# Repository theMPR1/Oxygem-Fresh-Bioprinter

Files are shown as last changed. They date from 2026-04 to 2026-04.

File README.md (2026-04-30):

# FRESH Bioprinter — Ender 5 Pro Conversion




Open-source design files for the conversion of a Creality Ender 5 Pro desktop 3D printer into a syringe extrusion bioprinter capable of FRESH (Freeform Reversible Embedding of Suspended Hydrogels) 3D bioprinting. Developed as part of a group project at the Department of Bioengineering, Imperial College London, under the supervision of Dr Ben Almquist.

The extruder is a modified Replistruder 5, with a GT2 belt drive replacing the original planetary gearbox to reduce mechanical dead zone,  an anti-backlash nut and preloaded carriage sliders to minimise axial freeplay. Motion control is provided by a Duet 3 Mainboard 6HC running RepRapFirmware 3.6.0.

For questions or issues, please open a GitHub Issue.

---

## Contributors

**Junyuan Guan** — Bioinks, Support Bath
**Magor Pocsveiler** — Extruder Design, Firmware, Mechanical Assembly  
**Vera Rachkova** — Extruder Design, Mechanical Assembly  
**Hannah Seo** — Bioinks, Support Bath  
**Hui Sin Phang** — Mechanical Build, Firmware  
**Saad S Ayub** — Presentation, Writing
**Zifeng T Guo** — Writing  
**Ricky Zhang** — Presentation, Writing  

**Supervisor:** Dr Ben Almquist, Department of Bioengineering, Imperial College London

---

## Repository Structure

```
├── CAD/
│   ├── STEP/          # Neutral format — open without Fusion 360
│   ├── STL/           # Print-ready files
│   └── Fusion/        # Native .f3d files
├── Firmware/
│   └── config/        # RepRapFirmware configuration files for Duet 3 6HC
├── Slicing/
│   └── CuraProfile/   # Ultimaker Cura profile for bioprinting
└── README.md
```

---

## Hardware

| Component | Details |
|---|---|
| Base printer | Creality Ender 5 Pro |
| Motion controller | Duet 3 Mainboard 6HC v1.02 + Duet 3 WiFi module |
| Extruder | Modified Replistruder 5 |
| Drive train | GT2 belt, 16T/48T pulleys (3:1 reduction), TR8×1.5 leadscrew |
| Syringe | Hamilton 1001 TLL (1 mL, PTFE luer-lock) |
| Needles | 34G (~90 µm ID) for acellular collagen; 30G (~150 µm ID) for cell-containing bioinks |
| Printed parts | PETG, Bambu Labs A1 |

---

## Modifications to the Replistruder 5

- Planetary gearbox and NEMA 11 replaced with GT2 belt drive and salvaged Ender 5 Pro NEMA 17
- Anti-backlash nut replacing standard TR8 lead nut
- Preloaded linear carriage sliders
- Screw-actuated belt tensioner with slotted motor mount and M3 lock screws
- TR8×1.5 leadscrew turned down on lathe (ends reduced to 5 mm, flat milled for set screw)
- Custom PETG adapter plate for mounting to Ender 5 Pro X-axis carriage

---

## Firmware

RepRapFirmware 3.x configured for Ender 5 Pro Cartesian kinematics on a Duet 3 6HC. Key parameters:

| Axis | Steps/mm | Microstepping | Max Speed | Acceleration |
|---|---|---|---|---|
| X | 80 | 64× | 30 mm/s | 50 mm/s² |
| Y | 80 | 64× | 30 mm/s | 50 mm/s² |
| Z | 400 | 16× | 10 mm/s | 20 mm/s² |
| E0 | 6400 | 16× | 5 mm/s | 10 mm/s² |

WiFi configured in access point mode (SSID: "FRESH Bioprinter", IP: 192.168.50.1).

Configuration files are in `/Firmware/config/`. Adapted from the open-source FF Finder bioprinter configuration published by the Shiwarski Tissue Engineering Lab (Zenodo DOI: [10.5281/zenodo.7496012](https://doi.org/10.5281/zenodo.7496012)).

---

## Slicing

Structures were sliced in Ultimaker Cura. The Cura profile is provided in `/Slicing/CuraProfile/`. Key print parameters:

| Parameter | Value | Rationale |
|---|---|---|
| Retraction distance | 0.05 mm | Prevents oozing at move boundaries |
| Z-hop | Enabled | Avoids disturbance of printed structures during travel |
| End retraction | 2 mm relative | Decompresses fluid column after print |
| X/Y microstepping | 64× | Increased positioning resolution |

---

## Bill of Materials

### Extruder & Motion Components (Magor Pocsveiler)

| Item | Qty | Supplier | Part No. | Link |
|---|---|---|---|---|
| TR8×1.5 Lead Screw Nut (Anti-backlash) | 1 | IGUS | JFRM-LC-0001-TR8X1.5 | [Link](https://www.igus.co.uk/articlerouter?artnr=JFRM-LC-0001-TR8X1.5) |
| TR8×1.5 Lead Screw 1000mm | 1 | IGUS | PTGSG-08X1.5-01-R-ES | [Link](https://www.igus.co.uk/articlerouter?artnr=PTGSG-08X1.5-01-R-ES) |
| Rail Carriage (Preloaded) | 2 | IGUS | NW-01-27-P | [Link](https://www.igus.co.uk/articlerouter?artnr=NW-01-27-P) |
| Rail 100mm | 1 | IGUS | NS-01-27 | [Link](https://www.igus.co.uk/articlerouter?artnr=NS-01-27) |
| Plain Flange Bearing | 2 | RS Components | 2725067 | [Link](https://uk.rs-online.com/web/p/products/2725067) |
| Plain Bearing | 2 | RS Components | 2725190 | [Link](https://uk.rs-online.com/web/p/products/2725190) |
| M3 Washers (pack of 100) | 1 | RS Components | 189620 | [Link](https://uk.rs-online.com/web/p/products/189620) |
| M3 Thin Nuts (pack of 250) | 1 | RS Components | 4830338 | [Link](https://uk.rs-online.com/web/p/products/4830338) |
| M3×0.5 16mm Socket Head (pack of 200) | 1 | RS Components | 4679818 | [Link](https://uk.rs-online.com/web/p/products/4679818) |
| M4×0.7 8mm Countersunk Head (pack of 100) | 1 | RS Components | 281215 | [Link](https://uk.rs-online.com/web/p/products/281215) |
| M4 Nuts (pack of 250) | 1 | RS Components | 525896 | [Link](https://uk.rs-online.com/web/p/products/525896) |
| 5mm Radial Bearing | 1 | RS Components | 74776 | [Link](https://uk.rs-online.com/web/p/products/74776) |
| Thrust Bearing 8mm Bore | 2 | Gears and Sprockets | 4255-282 | — |
| GT2 48T Pulley | 1 | Gears and Sprockets | 6001-061 | — |
| GT2 16T Pulley | 1 | Gears and Sprockets | 6001-001 | — |
| Duet 3 6HC Mainboard | 1 | Ooznest | — | [Link](https://ooznest.co.uk) |
| Duet 3 WiFi Module | 1 | Ooznest | — | [Link](https://ooznest.co.uk) |

### Consumables & Wet Lab (Vera Rachkova & Junyuan Guan)

| Item | Qty | Supplier | Part No. | Link |
|---|---|---|---|---|
| Hamilton 1000 Series Gastight Syringe TLL 1mL | 1 | Fisher Scientific UK | 81320 | [Link](https://www.fishersci.co.uk/shop/products/hamilton-1000-series-gastight-syringes-luer-lock-syringes-tll-termination-14/10772361) |
| 34G Dispensing Needle Techcon (pack of 50) | 1 | Adhesive Dispensing Ltd | TE734025PK | [Link](https://www.adhesivedispensing.co.uk/34g-precision-te-general-purpose-tip-lime-te734-9607-p.asp) |
| 30G Dispensing Needle Techcon (pack of 50) | 1 | Adhesive Dispensing Ltd | TE730050PK | [Link](https://www.adhesivedispensing.co.uk/30g-precision-te-general-purpose-tip-lavender-te730-9544-p.asp) |
| Blender (gelatin microparticle preparation) | 1 | Argos | — | [Link](https://www.argos.co.uk/product/2849520) |
| Gelatin from porcine skin, ~300 Bloom, Type A BioReagent (100g) | 1 | Sigma-Aldrich UK | G1890-100G | [Link](https://www.sigmaaldrich.com/GB/en/product/sigma/g1890) |
| Cell Strainer 40 µm nylon mesh, sterile (pack of 50) | 1 | Sigma-Aldrich UK | CLS431750 | [Link](https://www.sigmaaldrich.com/GB/en/product/sigma/cls431750) |

---

## Dependencies

- [RepRapFirmware 3.x](https://github.com/Duet3D/RepRapFirmware)
- [Ultimaker Cura](https://ultimaker.com/software/ultimaker-cura) (open-source)
- [Fusion 360](https://www.autodesk.com/products/fusion-360) (for native CAD files; STEP files provided for licence-free access)

---

## Related Publications

- Shiwarski, D.J. et al. "3D bioprinting of collagen-based high-resolution internally perfusable scaffolds for engineering fully biologic tissue systems." *Science Advances*, 2025. DOI: [10.1126/sciadv.adu5905](https://doi.org/10.1126/sciadv.adu5905)
- Tashman, J.W., Shiwarski, D.J., Feinberg, A.W. "A high performance open-source syringe extruder optimized for extrusion and retraction during FRESH 3D bioprinting." *HardwareX*, 2021, 9:e00170. DOI: [10.1016/j.ohx.2020.e00170](https://doi.org/10.1016/j.ohx.2020.e00170)
- Replistruder 5 design files: Zenodo DOI: [10.5281/zenodo.7135874](https://doi.org/10.5281/zenodo.7135874)
- FF Finder bioprinter config: Zenodo DOI: [10.5281/zenodo.7496012](https://doi.org/10.5281/zenodo.7496012)

---

## Acknowledgements

The extruder design presented here is derived from the Replistruder 5, developed by Joshua W. Tashman and Daniel J. Shiwarski in the Regenerative Biomaterials and Therapeutics Group, Department of Biomedical Engineering, Carnegie Mellon University, Pittsburgh, PA, USA, under the supervision of Professor Adam W. Feinberg. The original design files are archived at https://doi.org/10.5281/zenodo.7135874 and are released under a CC-BY-SA 4.0 licence. This work is likewise released under CC-BY-SA 4.0 in accordance with the terms of that licence.

---

## Licence

This work is licensed under Creative Commons Attribution-ShareAlike 4.0 International (CC-BY-SA 4.0). See [LICENSE](LICENSE) for the full licence text.



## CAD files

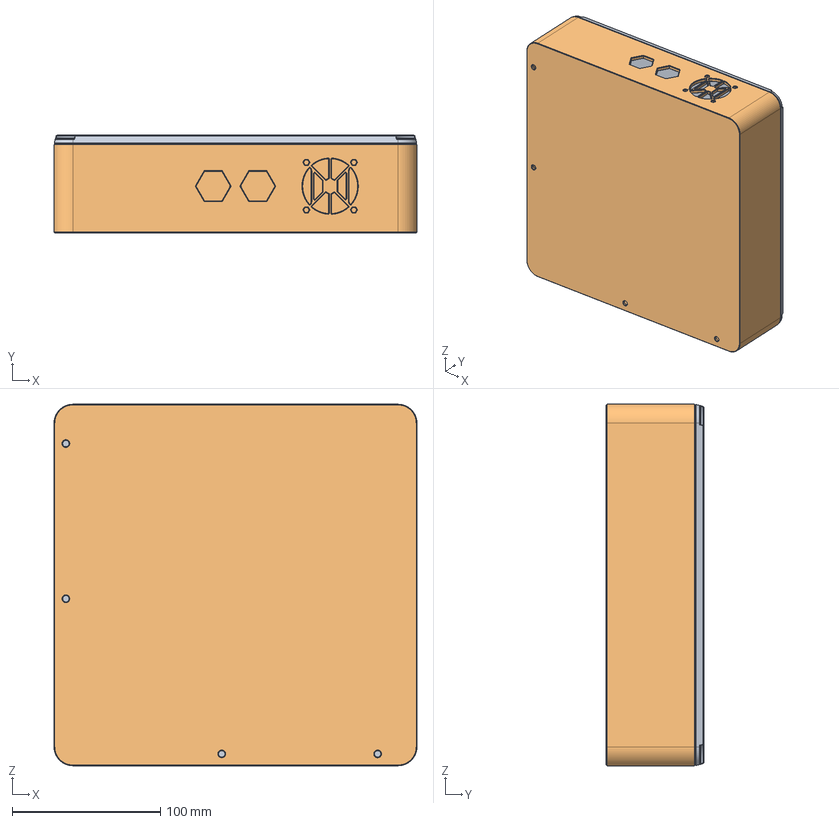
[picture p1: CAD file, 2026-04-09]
CAD/STEP/FBP-ENC-00-V1A-Enclosure_Assembly.stp
244.5 x 65.9 x 243.5 mm

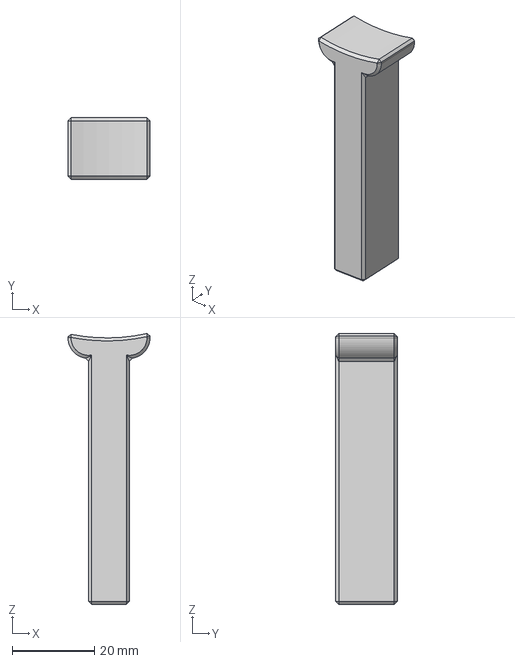
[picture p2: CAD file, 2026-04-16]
CAD/STEP/faxation stick.step
20.0 x 15.0 x 66.1 mm

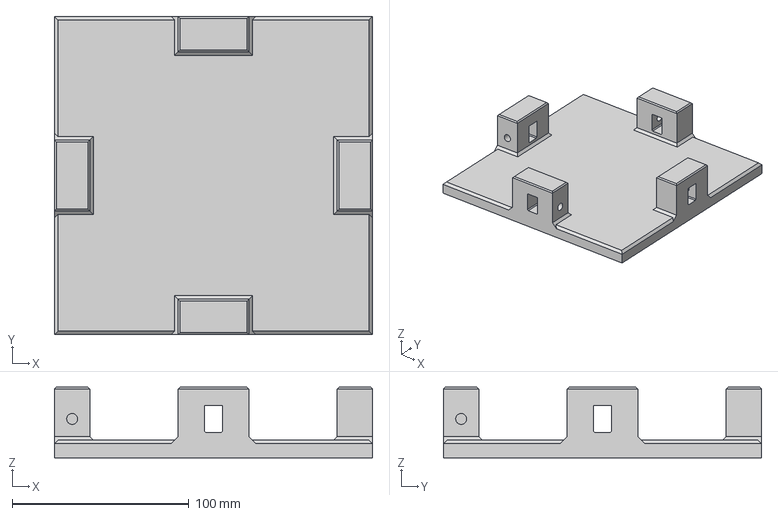
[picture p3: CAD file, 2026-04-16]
CAD/STEP/fixation plate.step
180.0 x 180.0 x 40.0 mm

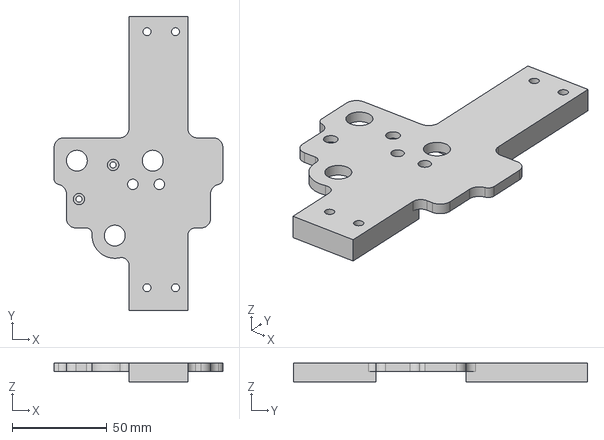
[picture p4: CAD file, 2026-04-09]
CAD/STEP/ender-5-pro-assem_hot-end-carriage-plate.step
89.0 x 155.0 x 10.0 mm

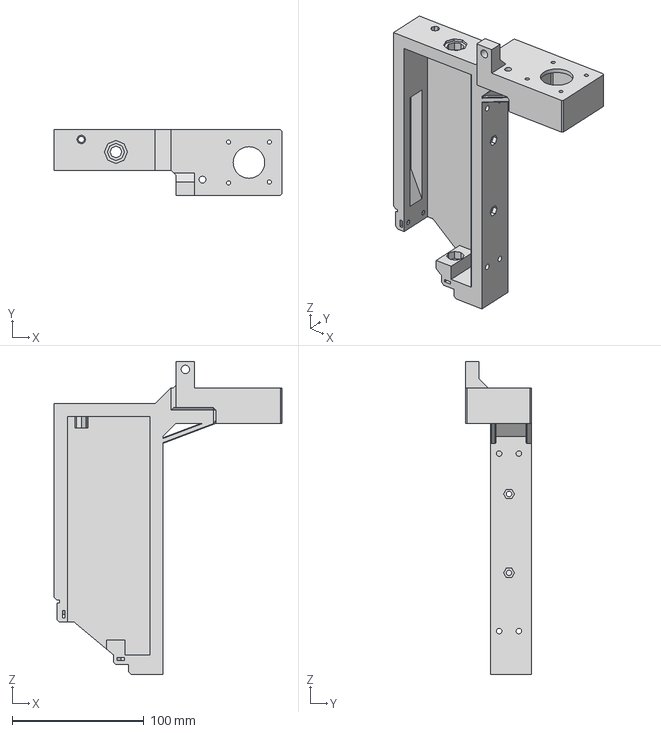
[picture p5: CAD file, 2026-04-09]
CAD/STEP/Rep5LinearSlides_Core.step
173.2 x 50.0 x 238.0 mm

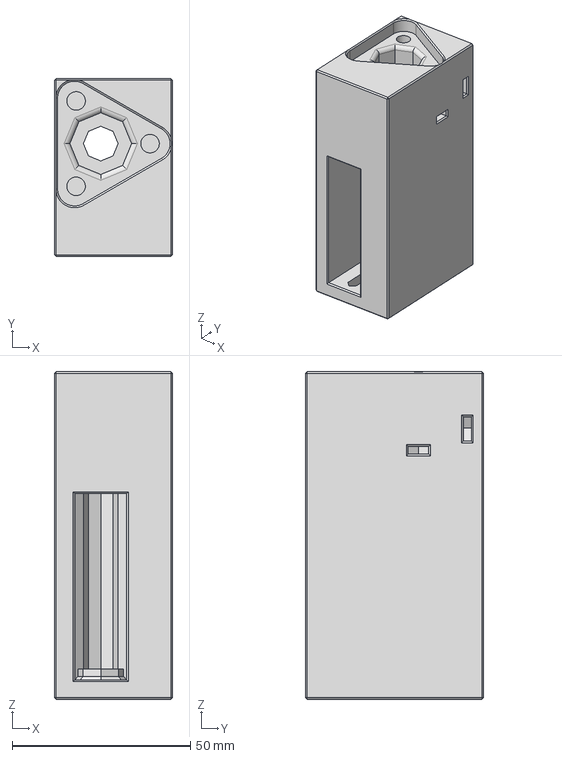
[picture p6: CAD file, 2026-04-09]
CAD/STEP/Rep5LinearSlides_Carriage.step
33.1 x 50.0 x 92.0 mm

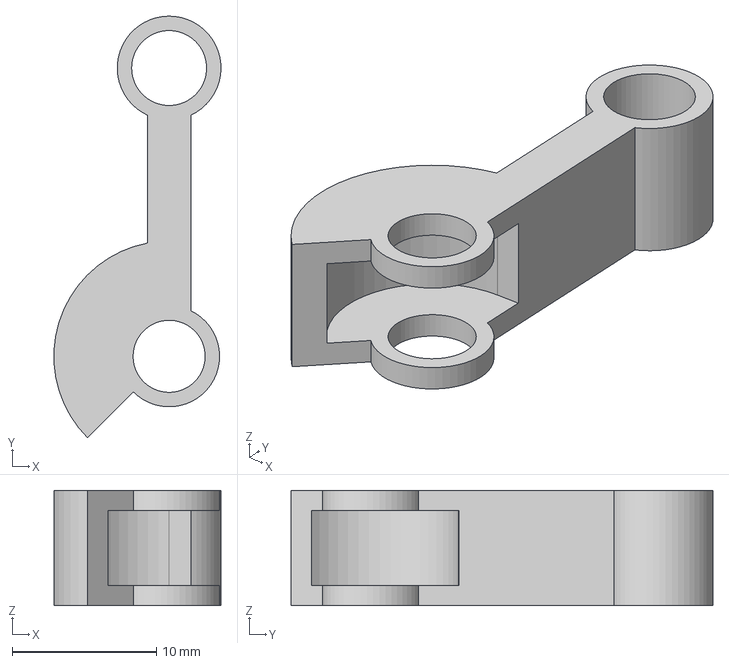
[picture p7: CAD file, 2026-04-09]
CAD/STEP/hinge.step
11.6 x 29.3 x 8.00 mm

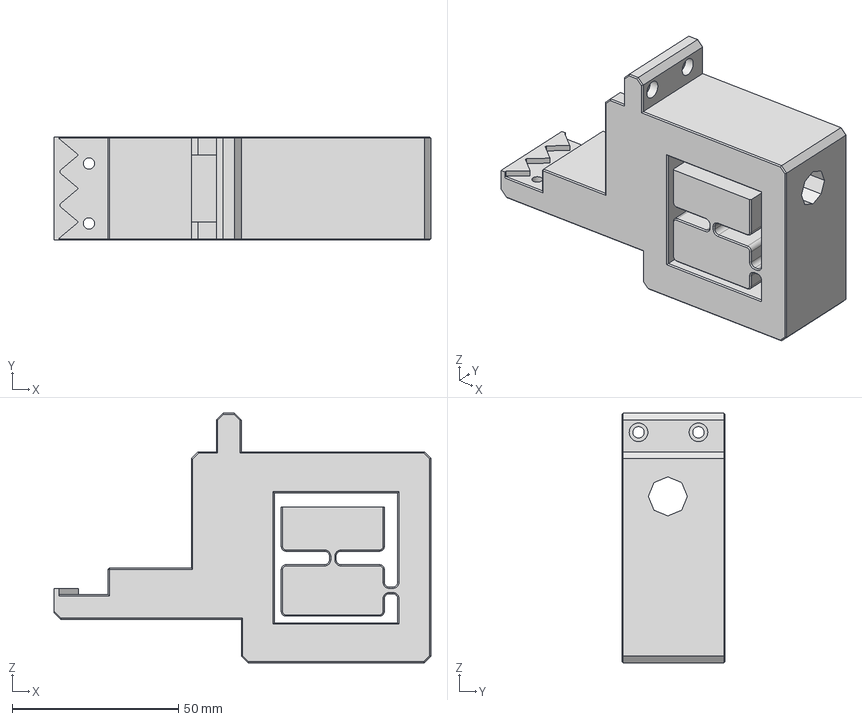
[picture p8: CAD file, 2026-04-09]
CAD/STEP/Rep5_MK3_FlexureMountBLANK.step
113.2 x 31.0 x 75.0 mm

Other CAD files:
CAD/Fusion/FBP-ENC-00-V1A-Enclosure_Assembly.f3d
CAD/Fusion/fixation plate final assempbly.f3z
CAD/STL/FBP-ENC-00-V1A-Enclosure_Assembly.stl
CAD/STL/Rep5LinearSlides_Carriage.stl
CAD/STL/Rep5LinearSlides_Core.stl
CAD/STL/Rep5_MK3_FlexureMountBLANK.stl
CAD/STL/ender-5-pro-assem_hot-end-carriage-plate.stl
CAD/STL/faxation stick.stl
CAD/STL/fixation plate.stl
CAD/STL/hinge.stl

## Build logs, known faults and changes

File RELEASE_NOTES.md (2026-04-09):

# Release Notes — v0.1.0 (Initial Zenodo Deposit)

**Date:** 2026-04-09  
**Status:** Initial public archive — further revisions planned

---

## Overview

This is the first archived release of the FRESH Bioprinter design files developed at the Department of Bioengineering, Imperial College London, under the supervision of Dr Ben Almquist. The repository contains the hardware design, firmware configuration, and slicing profile for converting a Creality Ender 5 Pro desktop 3D printer into a syringe extrusion bioprinter capable of FRESH (Freeform Reversible Embedding of Suspended Hydrogels) 3D bioprinting.

The extruder is a derivative of the Replistruder 5 (Tashman et al., *HardwareX* 2021; Zenodo: 10.5281/zenodo.7135874), modified to replace the original planetary gearbox with a GT2 belt drive, and to incorporate an anti-backlash nut and preloaded carriage sliders. Motion control is provided by a Duet 3 Mainboard 6HC running RepRapFirmware 3.6.0.

---

## Contents of This Release

| Directory | Contents |
|---|---|
| `CAD/Fusion/` | Native Autodesk Fusion 360 design files (`.f3d`, `.f3z`) |
| `CAD/STEP/` | Neutral-format STEP files for licence-free CAD access |
| `CAD/STL/` | Print-ready STL files for all custom printed parts |
| `Firmware/config/` | RepRapFirmware 3.x configuration for Duet 3 6HC (zipped) |
| `Slicing/CuraProfile/` | Ultimaker Cura profile optimised for syringe extrusion |

---

## Known Limitations and Pending Work

This release is an initial deposit made to establish a citable DOI for the project record. The following items are incomplete or subject to revision in subsequent releases:

- **Contributor roles** — several contributor descriptions in `README.md` are placeholders pending confirmation from team members.
- **Project report** — `Report Place Holder.pdf` is a placeholder; the final project report will replace this in a future release.
- **CAD completeness** — the enclosure assembly (`FBP-ENC-00-V1A`) is at revision V1A and may be updated as the design is refined.
- **Firmware** — configuration files are provided as an unversioned zip archive; individual files and version tagging will be added in future releases.
- **Bill of materials** — some supplier part numbers and links are listed as approximate or without a part number (e.g. Duet 3 boards from Ooznest, thrust bearings from Gears and Sprockets); these will be confirmed in subsequent releases.
- **Zenodo DOI** — the DOI badge in `README.md` contains a placeholder (`zenodo.TODO`) that will be updated once the Zenodo record is published.

Users requiring a fully validated, stable release should await a subsequent version. This deposit is intended to establish provenance and enable citation during the project's active development phase.

---

## Versioning

Releases will follow semantic versioning (`MAJOR.MINOR.PATCH`):

- `v0.x.x` — development releases; files and design decisions may change without backwards compatibility guarantees.
- `v1.0.0` — first stable release, corresponding to the finalised project submission.

---

## How to Cite

If you use these files, please cite this Zenodo record directly. A suggested citation will appear on the Zenodo landing page once the DOI is activated.

This work is derived from the Replistruder 5; please also cite:

> Tashman, J.W., Shiwarski, D.J., Feinberg, A.W. "A high performance open-source syringe extruder optimized for extrusion and retraction during FRESH 3D bioprinting." *HardwareX*, 2021, 9:e00170. DOI: [10.1016/j.ohx.2020.e00170](https://doi.org/10.1016/j.ohx.2020.e00170)

---

## Licence

CC-BY-SA 4.0 — see `LICENSE` for full text. Derivative works must be released under the same licence, in accordance with the upstream Replistruder 5 licence terms.

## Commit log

2026-04-09 Added all Files
    V0.1 Multiple TODOs including re-uploading profile and firmware to match post calibration values and adding final report inplace of current placeholder
    [FBP-ENC-00-V1A-Enclosure_Assembly.f3d, FBP-ENC-00-V1A-Enclosure_Assembly.stl, FBP-ENC-00-V1A-Enclosure_Assembly.stp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]
2026-04-16 Presubmission Refresh
    [faxation stick.step, faxation stick.stl, fixation plate final assempbly.f3z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]

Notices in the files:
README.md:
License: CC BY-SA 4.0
